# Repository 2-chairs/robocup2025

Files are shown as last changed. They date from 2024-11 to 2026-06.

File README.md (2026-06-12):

# robocup2025
# Team 2-Chairs - RoboCup Singapore Soccer Open Junior 

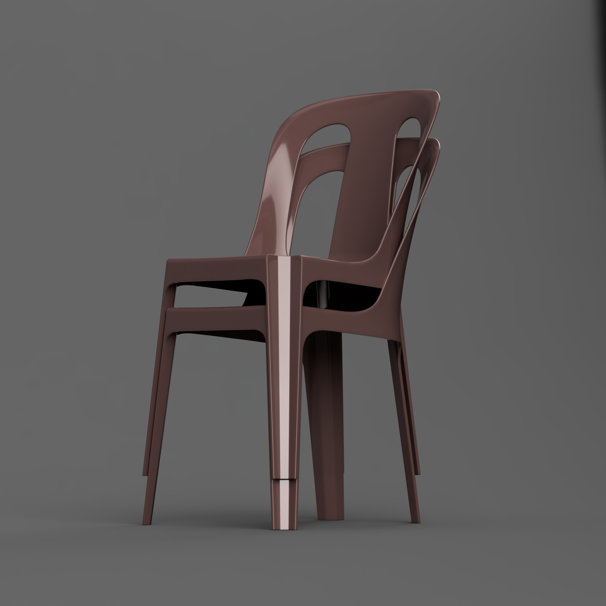
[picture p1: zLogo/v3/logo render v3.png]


*Repository for the official electronic, mechanical, and software files of Team 2-Chairs.*

## About

This repository is for **Team 2-Chairs**, a Singapore RoboCup Open Soccer Junior team, and includes relevant design files and resources.

## Repository Structure

- **Electronics/** - PCB designs, schematics, and component footprints. (Note: regarding layer1 and layer3 pcb files, a critical mistake had been made where the Xiao Esp32c3 was powered through 3v3 pin with 3v3, when it should have been through 5v VIN pin with 5v; regarding layer3 the camera should be powered through 5v instead of 3v3 too)
- **Mechanical/** - 3D-printable files in **.3MF** and **.STL** formats; includes rendered images of the robot and its mirrored counterpart for reference. 
- **Code/** - Firmware and control software for the robot. (sub-par quality, some code untested)
- **Logo/** - Official team branding and design assets.

## Credits 
In the grand tapestry of our design endeavor, we owe a debt of profound gratitude to the esteemed teams of Sentinels Robotics, ducc. & Butter Chicken, whose brilliant schematics and designs (and potentially code) have guided our efforts.

## License & Copyright

© 2025 Team 2-Chairs. All rights reserved, except where otherwise stated. 

<p xmlns:cc="http://creativecommons.org/ns#" ><a rel="cc:attributionURL" href="https://github.com/2-chairs/robocup2025">This work</a> by <span property="cc:attributionName">Ng Chen-Xuan, Euston Tan, Chen YiKai</span> is licensed under <a href="https://creativecommons.org/licenses/by-nc-sa/4.0/?ref=chooser-v1" target="_blank" rel="license noopener noreferrer" style="display:inline-block;">Creative Commons Attribution-NonCommercial-ShareAlike 4.0 International</a></p>

---

**"Two chairs, twice the betterness"**

*Written by ChatGPT, Edited by human*

<p>Retired as of 6 April 2025</p>

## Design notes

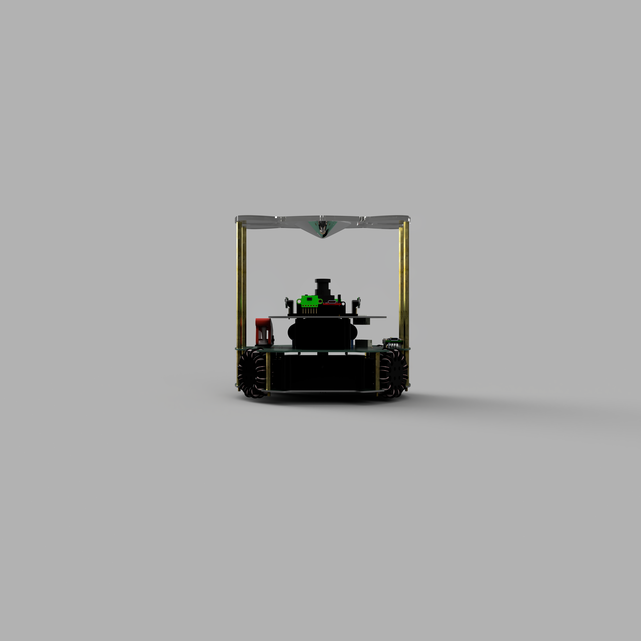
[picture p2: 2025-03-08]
Mechanical/Renders/one more bot v220 pic.png

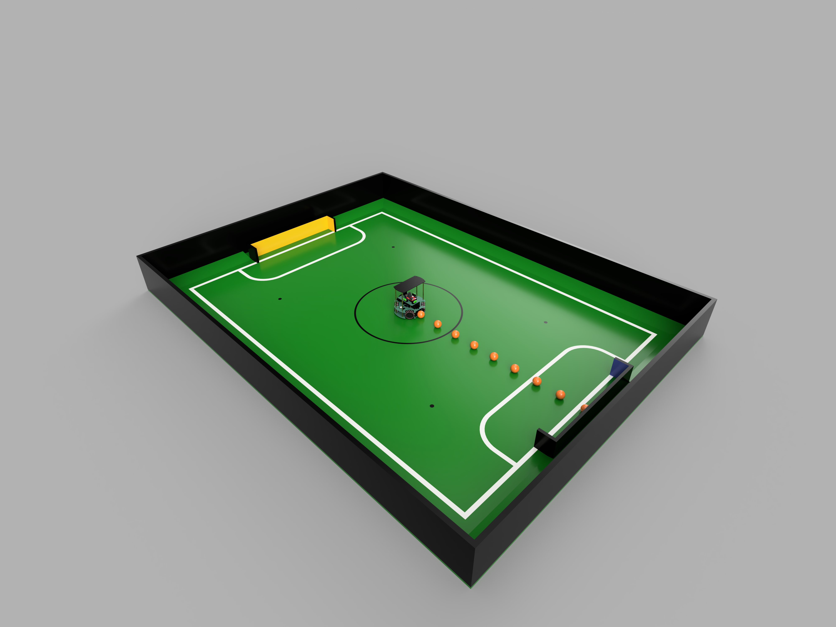
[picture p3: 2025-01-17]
Mechanical/Renders/bot_and_playfield.png

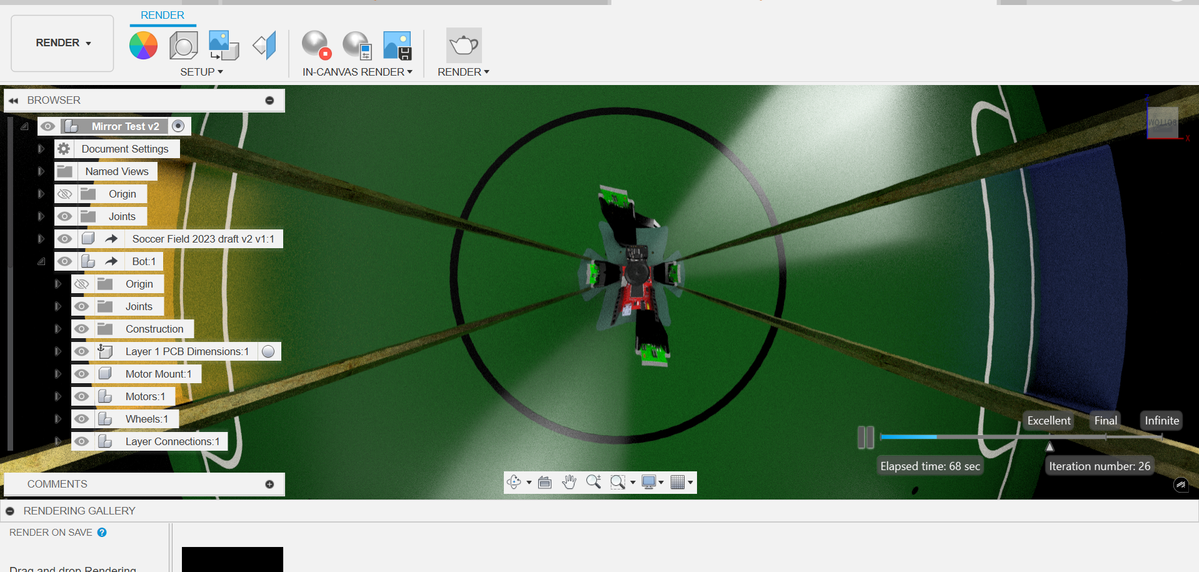
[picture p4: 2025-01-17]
Mechanical/Renders/Mirror/Mirror simulation screenshot.png

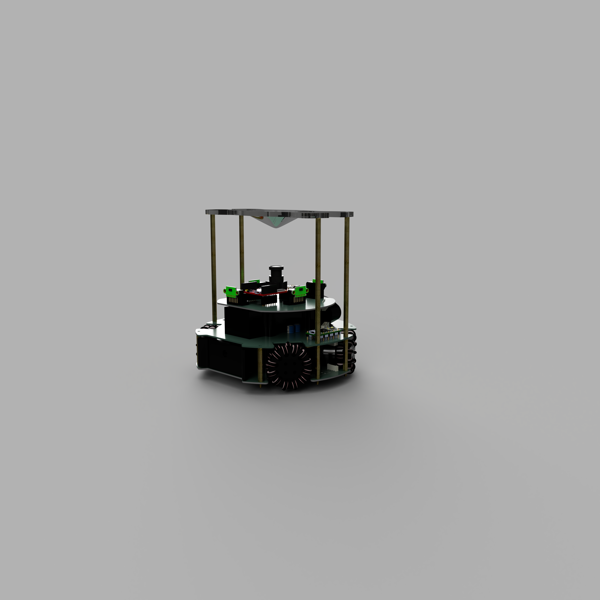
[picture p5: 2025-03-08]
Mechanical/Renders/another bot v220 pic.png

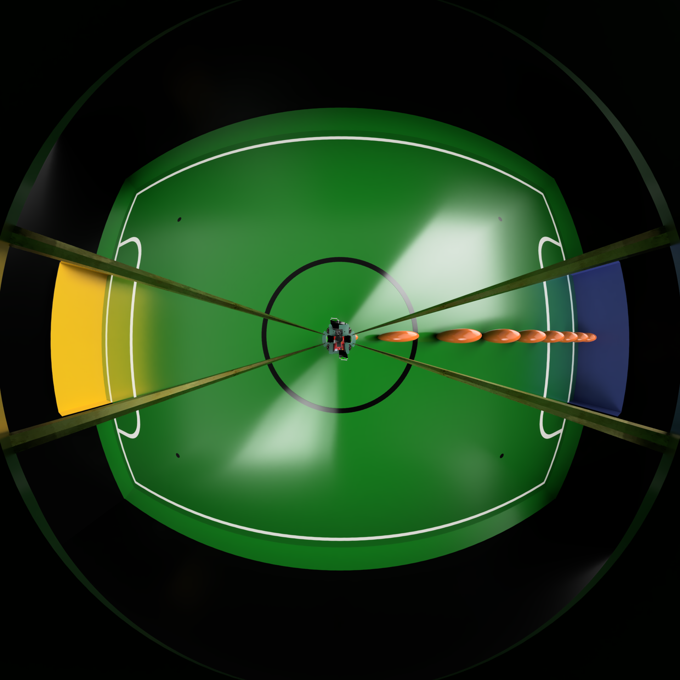
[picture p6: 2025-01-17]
Mechanical/Renders/Mirror/mirrortest3.png

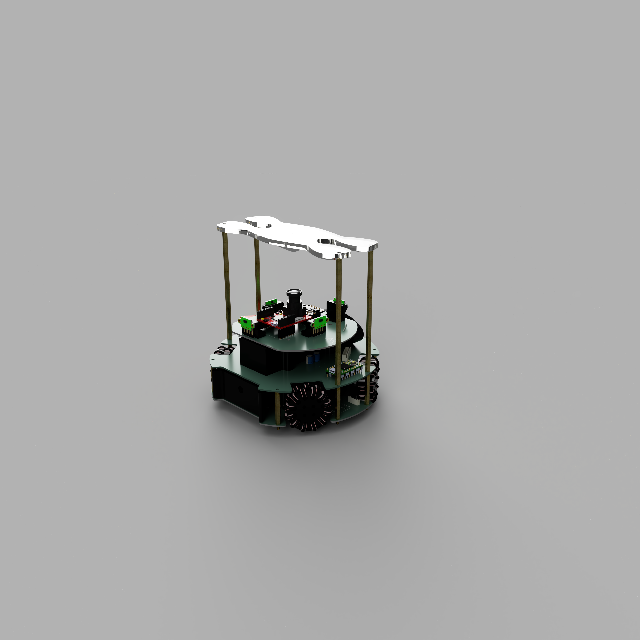
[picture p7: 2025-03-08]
Mechanical/Renders/bot v220 pic.png

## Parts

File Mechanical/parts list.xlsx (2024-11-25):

Parts list
Part type | About | Specification | Material | Manufactoring method | Dimensions/mm (If applicable) | Price/single qty | Price/buying qty | buying qty/bag | qty needed | buying qty | Total price | Buying link
O Rings | o rings as tyres for moniwheel rollers | v cool | nitrile rubber | idk just buying it | OD: 9.3, ID: 6.1, Thickness: 1.6 | 0.121 | 6.07 | 50 | 360 | 8 | 48.56 | https://sg.rs-online.com/web/p/gaskets-o-rings/0128811?gb=s
Dowel Pins | Pin to act as axel for omniwheel rollers | who cares | 304 Stainless Steel | not my problem | Diameter: 2, Length: 6 | 0.06 | 3 | 50 | 360 | 8 | 24 | https://www.lazada.sg/products/nindejin-5-50pcs-dowel-pins-304-stainless-steel-m2-m25-m3-m4-m5-m6-parallel-pins-fastener-solid-cylinder-pin-gb119-i1940710543-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
Motors | driving motors duh? | Chihai motors (CHR-GM25-370) | not our problem proably metals n stuff | actually though whats this column for |  | 12.08 | 12.08 | 1 | 9 | 9 | 108.72 | https://www.aliexpress.com/item/4000981259486.html?utparam-url=scene%3Asearch%7Cquery_from%3A

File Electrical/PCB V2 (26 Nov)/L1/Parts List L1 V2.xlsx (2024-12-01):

Parts list | status
Part |  | Model | Package | Weight | Dimensions (LxWxH) in mm | Price | Data Sheet
MCU for L1 | not required to buy | XIAO 102010428 | NA | no clue |  | not required as in lab
Photoresistor | to buy | ALS-PT19-315C/L177/TR8 | NA | refer to ducc | 0.8 x 0.6 x 1.7 | $0.05
LEDS | lab | kicad smd thingy | NA | NA | 1.6mm x 0.8mm x 0.6 mm | 0.05( actl 0 cos lab have)
Muxes | to buy | CD74HC4067SM |  |  | 7.4 X 6 X 1.4 | 2.0 to 4 | https://www.snapeda.com/parts/CD74HC4067SM96G4/Texas%20Instruments/datasheet/

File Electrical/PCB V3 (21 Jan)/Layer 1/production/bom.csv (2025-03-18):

Designator | Footprint | Quantity | Value | LCSC Part #
C1, C10, C11, C12, C13, C14, C15, C16, C17, C18, C19, C2, C20, C21, C22, C23, C24, C25, C26, C27, C28, C29, C3, C30, C31, C32, C4, C5, C6, C7, C8, C9 | 0603 | 32 | 1uF
C33, C34 | 0603 | 2 | .1uF
C35 | 0603 | 1 | 0.1uF | C3011705
C36 | CP_Radial_D8.0mm_P3.50mm | 1 | 100uF | C249586
C37, C38, C39, C41, C42, C43 | CP_Radial_D16.0mm_P7.50mm | 6 | 1000uF | C249586
C40 | 0603 | 1 | 0.68uF | C59782
C44 | 0603 | 1 | 1500pF | C107060
D1 | D_DO-201AD_P15.24mm_Horizontal | 1 | 1N5401 | C179506
D2 | TO-220-2_Vertical | 1 | MBR745
J1 | JST_EH_B4B-EH-A_1x04_P2.50mm_Vertical | 1 | Conn_01x04
J2 | AMASS_XT30UPB-M_1x02_P5.0mm_Vertical | 1 | Conn_01x02
L33 | L_APV_APH1040 | 1 | 33uH | C2875750
LED1, LED10, LED11, LED12, LED13, LED14, LED15, LED16, LED17, LED18, LED19, LED2, LED20, LED21, LED22, LED23, LED24, LED25, LED26, LED27, LED28, LED29, LED3, LED30, LED31, LED32, LED4, LED5, LED6, LED7, LED8, LED9 | LED_PLCC_2835 | 32 | WHITE 3528
LED_1, LED_10, LED_11, LED_12, LED_13, LED_14, LED_15, LED_16, LED_17, LED_18, LED_19, LED_2, LED_20, LED_21, LED_22, LED_23, LED_24, LED_25, LED_26, LED_27, LED_28, LED_29, LED_3, LED_30, LED_31, LED_32, LED_4, LED_5, LED_6, LED_7, LED_8, LED_9 | XDCR_ALS-PT19-315C_L177_TR8 | 32 | R_Photo
Q2 | TO-220-3_Vertical | 1 | STP75NF75 | C13678
Q4 | SOT95P237X112-3N | 1 | IRLML6344TRPBF
R1, R10, R11, R12, R13, R14, R15, R16, R17, R18, R19, R2, R20, R21, R22, R23, R24, R25, R26, R27, R28, R29, R3, R30, R31, R32, R4, R5, R6, R7, R8, R9 | 0603 | 32 | 0R39
R33, R34 | 0603 | 2 | 3k24
R35 | 0603 | 1 | 36.9K/56k | C23082
R36 | 0603 | 1 | 2K/2.94k | C22843
R37, R43 | 0603 | 2 | 10k
R38 | 0603 | 1 | 3K | C137748
R39 | 0603 | 1 | 10K | C25804
R40 | 0603 | 1 | 470R | C21190
R41 | 0603 | 1 | 1K | C21190
R42 | 0603 | 1 | 20R | C22950
TP1 | testpoint_2pad_2-chairs. | 1 | Led 3v3 & Gnd TP
U1 | VREG_TPS79625KTTR | 1 | LM2587S-ADJ
U2, U3 | SOP65P780X200-24N | 2 | CD74HC4067SM
U4 | AMASS_XT30U-M_1x02_P5.0mm_Vertical | 1 | XT30UPB-M
U5 | XiaoSeeedStudioEsp32 | 1 | 113991054

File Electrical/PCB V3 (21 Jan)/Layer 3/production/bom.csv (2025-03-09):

Designator | Footprint | Quantity | Value | LCSC Part #
J1, J3, J4, J5 | PinHeader_1x06_P2.54mm_Vertical | 4 | Conn_01x06
J2 | JST_XH_B8B-XH-A_1x08_P2.50mm_Vertical | 1 | Conn_02x08_Odd_Even
R1, R2, R3, R4, R5, R6, R7, R8 | 0603 | 8 | R
U1 | OPENMV_M7 | 1 | ~
U2 | MODULE_113991054 | 1 | 113991054
U3 | MODULE_4754 | 1 | 4754

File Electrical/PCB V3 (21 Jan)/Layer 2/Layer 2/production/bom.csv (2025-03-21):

Designator | Footprint | Quantity | Value | LCSC Part #
A1 | MODULE_DEV-15583 | 1 | TEENSY_4.0
C1, C2 | 0603 | 2 | 10u
C10, C14, C4, C7 | CP_Radial_D8.0mm_P3.50mm | 4 | 470u | C5162352
C3, C6 | 0603 | 2 | 10n
C5, C8 | CP_EIA-7343-15_Kemet-W_Pad2.25x2.55mm_HandSolder | 2 | 220u
D1, D2 | DIOM5025X220N | 2 | SS54
J1 | AMASS_XT60-M | 1 | XT60-M
J2 | JST_XH_B8B-XH-A_1x08_P2.50mm_Vertical | 1 | Conn_02x04_Odd_Even
J3 | JST_XH_B4B-XH-A_1x04_P2.50mm_Vertical | 1 | Conn_01x04
J5 | SolderWire-0.1sqmm_1x02_P3.6mm_D0.4mm_OD1mm | 1 | Conn_01x02
L1, L2 | 0630 One Piece Inductor | 2 | 15uH
Q1, Q2, Q3, Q4 | 8-DFN (5x6) | 4 | AON6354
R1, R12, R13, R2, R20, R21, R29, R30 | res0603 | 8 | 3K3
R10, R28 | 0603 | 2 | 10K
R11 | 0603 | 1 | 5k9
R14, R22, R3, R31 | res0603 | 4 | 10K
R15, R16, R17, R18, R19, R23, R24, R25, R26, R27, R32, R33, R34, R35, R36, R38, R4, R5, R6, R7, R8 | res0603 | 21 | 1K
R37 | 0603 | 1 | 3K24
SW2 | AMASS_XT30PW-M_1x02_P2.50mm_Horizontal | 1 | SW_SPST
SW3 | JST_XH_B2B-XH-A_1x02_P2.50mm_Vertical | 1 | SW_SPST
TP1 | 14 AWG Testpoint (Compact) | 1 | TestPoint_2Pole
TP2, TP3 | 14 AWG Testpoint (Vertical) | 2 | TestPoint_2Pole
U1, U12, U5, U9 | fixed -onenew-newer-newest | 4 | VNH5019ATR-E
U2, U3 | TI_SO-PowerPAD-8 | 2 | TPS5430DDAG4
U4, U6, U7, U8 | XT30UPB-M | 4 | XT30UPB-M

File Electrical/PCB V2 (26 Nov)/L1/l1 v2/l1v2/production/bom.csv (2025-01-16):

Designator | Footprint | Quantity | Value | LCSC Part #
C1, C10, C11, C12, C13, C14, C15, C16, C17, C18, C19, C2, C20, C21, C22, C23, C24, C25, C26, C27, C28, C29, C3, C30, C31, C32, C4, C5, C6, C7, C8, C9 | 0603 | 32 | 1uF
J1 | SolderWirePad_1x01_SMD_1x2mm | 1 | Conn_01x01_Socket
J2 | SolderWire-0.5sqmm_1x01_D0.9mm_OD2.1mm | 1 | Conn_01x01_Socket
J3 | PinHeader_1x02_P1.00mm_Horizontal | 1 | Conn_01x02
L1, L10, L11, L12, L13, L14, L15, L16, L17, L18, L19, L2, L20, L21, L22, L23, L24, L25, L26, L27, L28, L29, L3, L30, L31, L32, L4, L5, L6, L7, L8, L9 | 0805 | 32 | 10µH
LED1, LED10, LED11, LED12, LED13, LED14, LED15, LED16, LED17, LED18, LED19, LED2, LED20, LED21, LED22, LED23, LED24, LED25, LED26, LED27, LED28, LED29, LED3, LED30, LED31, LED32, LED4, LED5, LED6, LED7, LED8, LED9 | LED_PLCC_2835 | 32 | WHITE 3528
LED_1, LED_10, LED_11, LED_12, LED_13, LED_14, LED_15, LED_16, LED_17, LED_18, LED_19, LED_2, LED_20, LED_21, LED_22, LED_23, LED_24, LED_25, LED_26, LED_27, LED_28, LED_29, LED_3, LED_30, LED_31, LED_32, LED_4, LED_5, LED_6, LED_7, LED_8, LED_9 | XDCR_ALS-PT19-315C_L177_TR8 | 32 | R_Photo
R1, R10, R11, R12, R13, R14, R15, R16, R17, R18, R19, R2, R20, R21, R22, R23, R24, R25, R26, R27, R28, R29, R3, R30, R31, R32, R4, R5, R6, R7, R8, R9 | 0603 | 32 | 0R39
SW1 | Nidec_Copal_CAS-120A | 1 | SW_SPDT
TP1, TP2 | TestPoint_2Pads_Pitch2.54mm_Drill0.8mm | 2 | TestPoint
U1 | MCU_Seeed_ESP32C3 | 1 | 102010428
U2, U3 | SOP65P780X200-24N | 2 | CD74HC4067SM
U4 | XT30UPB-M | 1 | XT30UPB-M

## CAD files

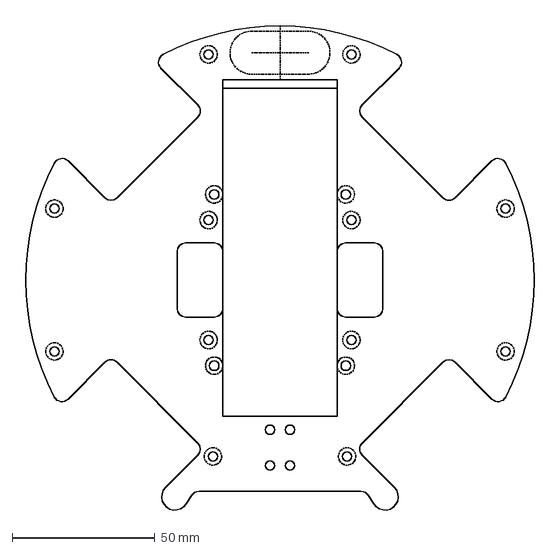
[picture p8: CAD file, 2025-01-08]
Electrical/PCB V2 ( 26 Nov)/L2/L2 Layout.dxf
184.7 x 173.1 mm

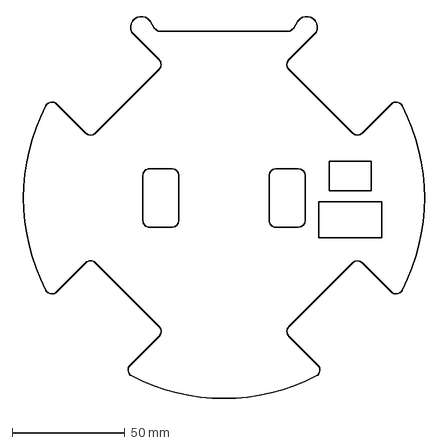
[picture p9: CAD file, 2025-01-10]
Electrical/PCB V2 (26 Nov)/L2/L2 Edgecut DXF.dxf
184.7 x 173.1 mm

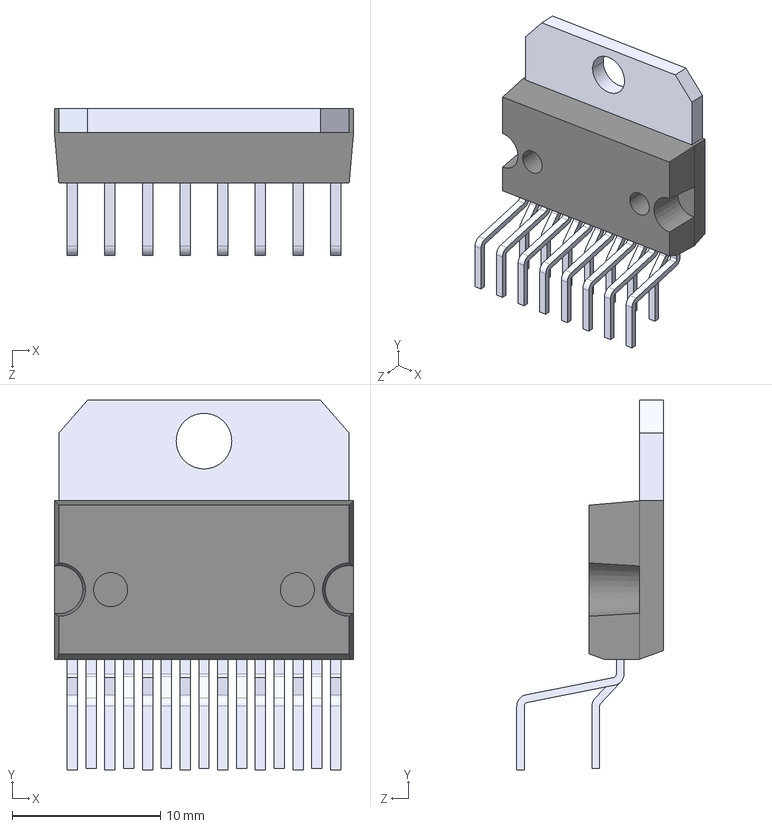
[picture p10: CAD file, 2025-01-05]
Electrical/PCB V2 (26 Nov)/L2/References/L298N/L298N.step
20.2 x 25.0 x 9.89 mm

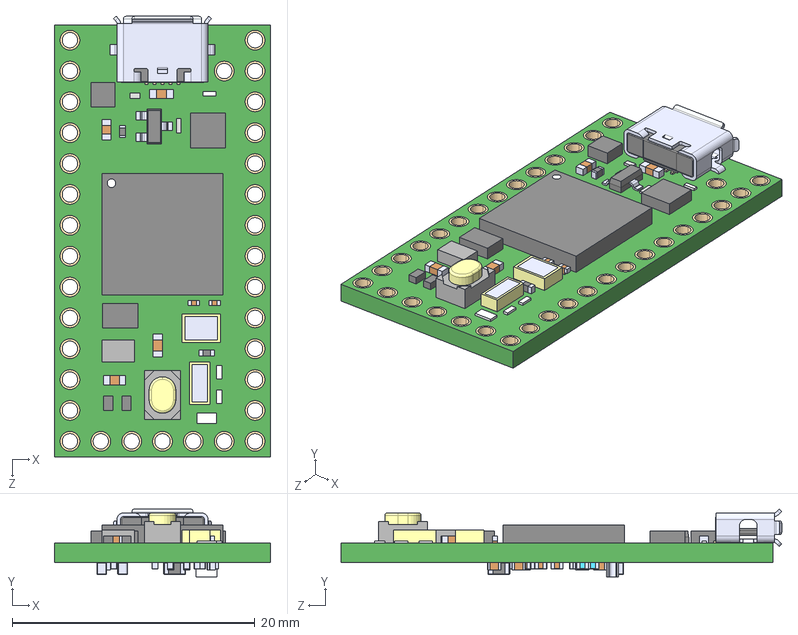
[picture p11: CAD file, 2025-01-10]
Electrical/PCB V2 (26 Nov)/L2/References/Teensy Symbol/DEV-15583.step
17.8 x 5.58 x 36.3 mm
DEV-15583 board
C5-C18 (0.55mm)
C20-C24 (0.65)
R1-R3 (0.4inch)_1269AS-H-3R3M=P2
L1^DEV-15583 ASS
C x 2
C2

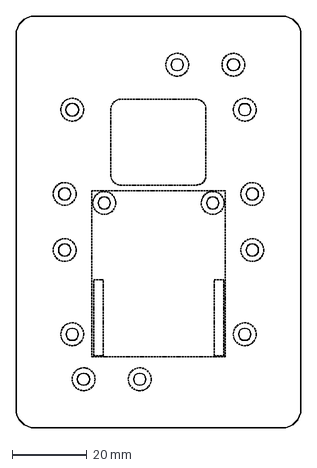
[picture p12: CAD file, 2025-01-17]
Electrical/PCB V2 (26 Nov)/L3/DXFs/Drawings/Drawings v0.dxf
76.1 x 110.0 mm

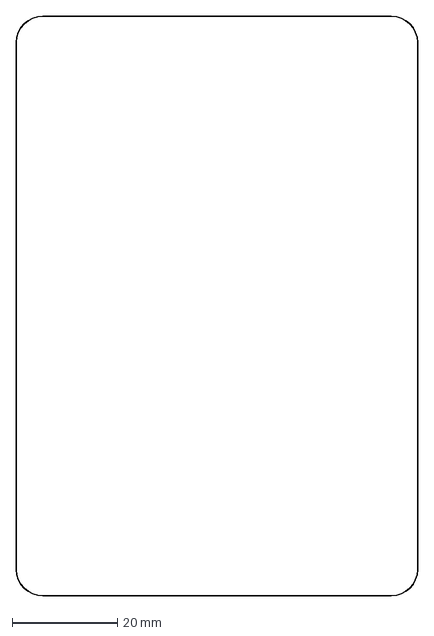
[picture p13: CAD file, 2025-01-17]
Electrical/PCB V2 (26 Nov)/L3/DXFs/Edgecuts/Edgecuts v0.dxf
76.1 x 110.0 mm

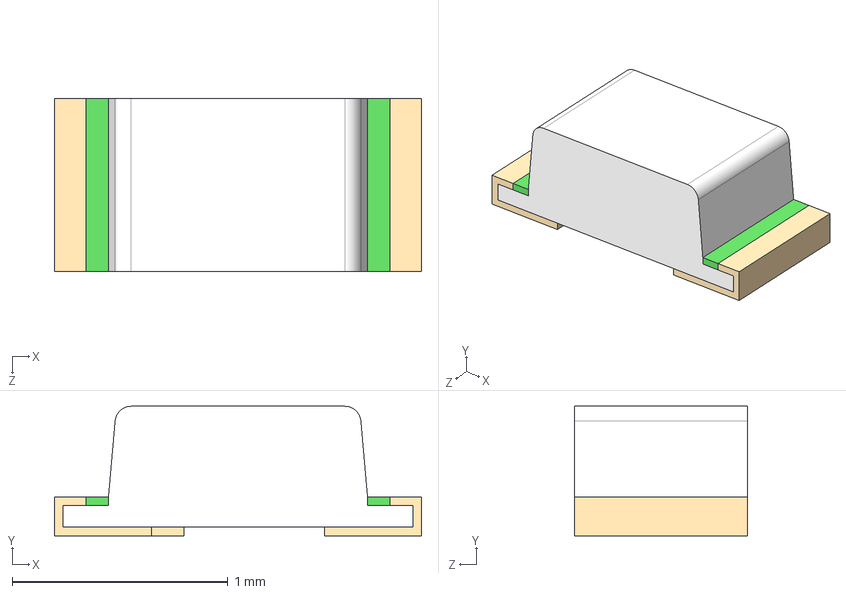
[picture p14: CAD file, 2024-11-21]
Electrical/PCB V2 (26 Nov)/References/ALS-PT19-315C_L177_TR8/ALS-PT19-315C_L177_TR8.step
1.70 x 0.6 x 0.8 mm

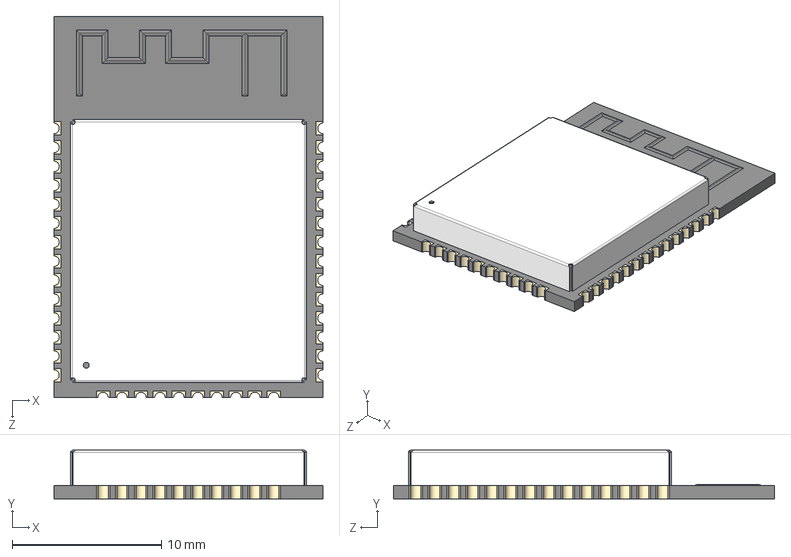
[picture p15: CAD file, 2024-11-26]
Electrical/PCB V2 (26 Nov)/References/ESP32-WROOM-32D-N4/ESP32-WROOM-32D-N4.step
18.0 x 3.25 x 25.5 mm

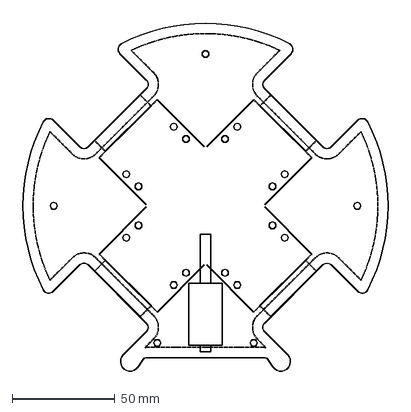
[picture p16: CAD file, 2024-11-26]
Electrical/PCB V2 (26 Nov)/References/L1 Layout.dxf
184.7 x 173.1 mm

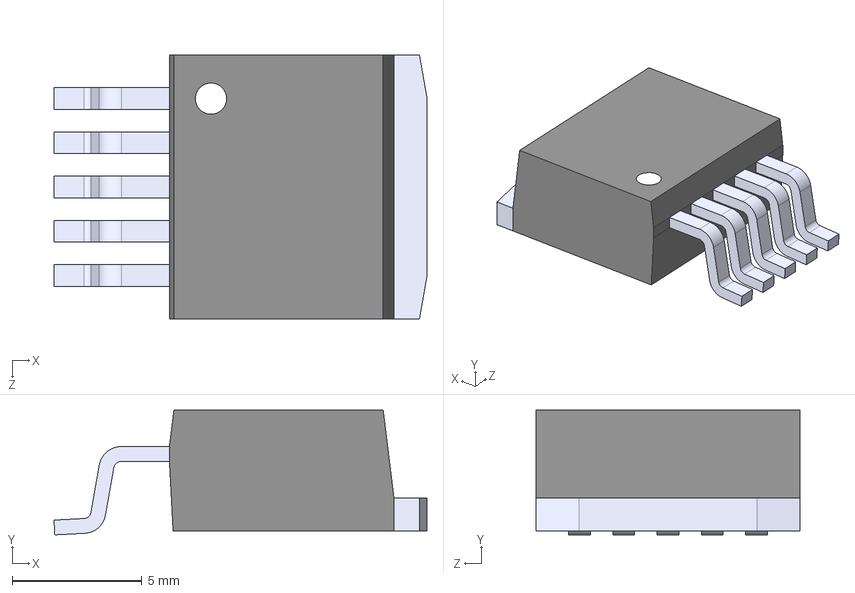
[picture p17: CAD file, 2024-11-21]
Electrical/PCB V2 (26 Nov)/References/LM2596ADJ/LM2596ADJ.step
14.4 x 4.80 x 10.2 mm

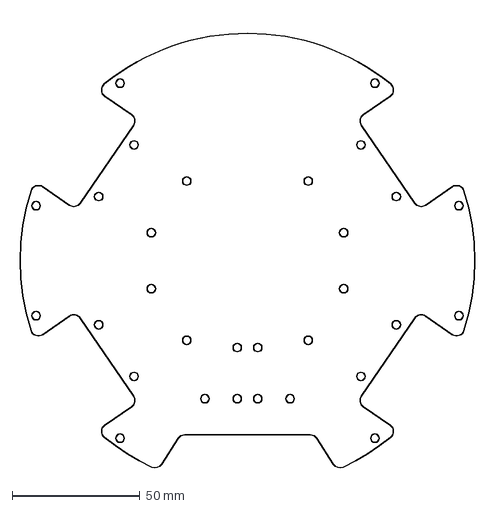
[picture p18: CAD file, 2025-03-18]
Electrical/PCB V3 (21 Jan)/Layer 1/Sub-References/OneAndOnlyDxf v10dxf.dxf
180.9 x 177.0 mm

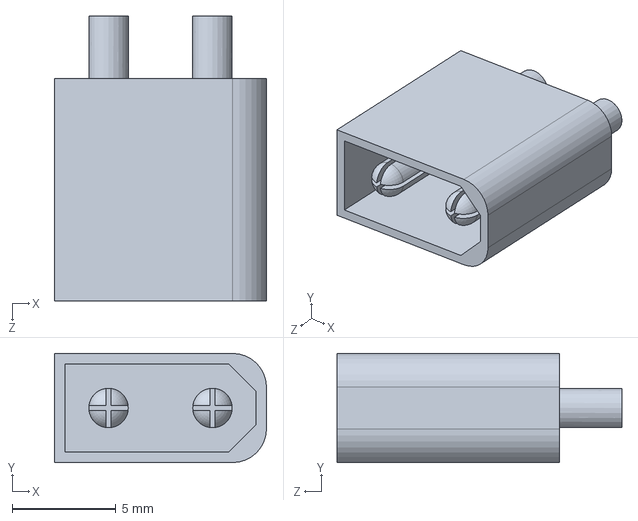
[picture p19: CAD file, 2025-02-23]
Electrical/PCB V3 (21 Jan)/Layer 1/Sub-References/xt30/xt30male/XT30U-M_NEW.SLDPRT
10.2 x 5.25 x 13.7 mm

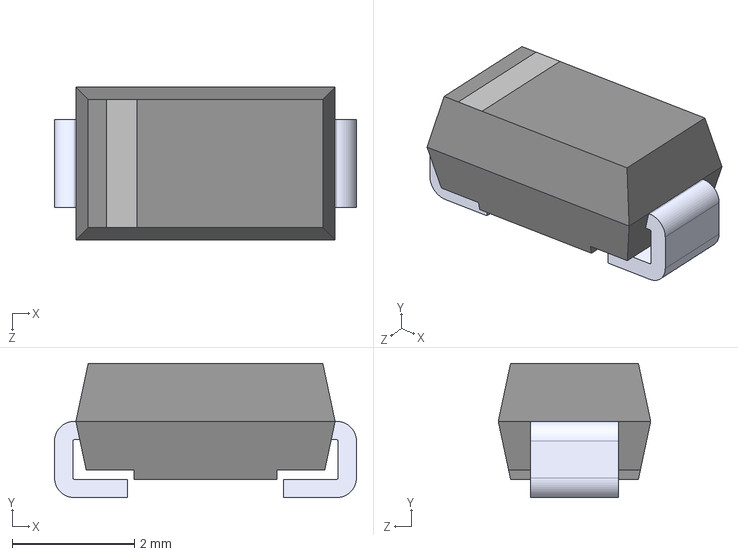
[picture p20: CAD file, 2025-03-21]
Electrical/PCB V3 (21 Jan)/Layer 2/Layer 2/3dmodels/SS54-HF.step
4.95 x 2.20 x 2.50 mm

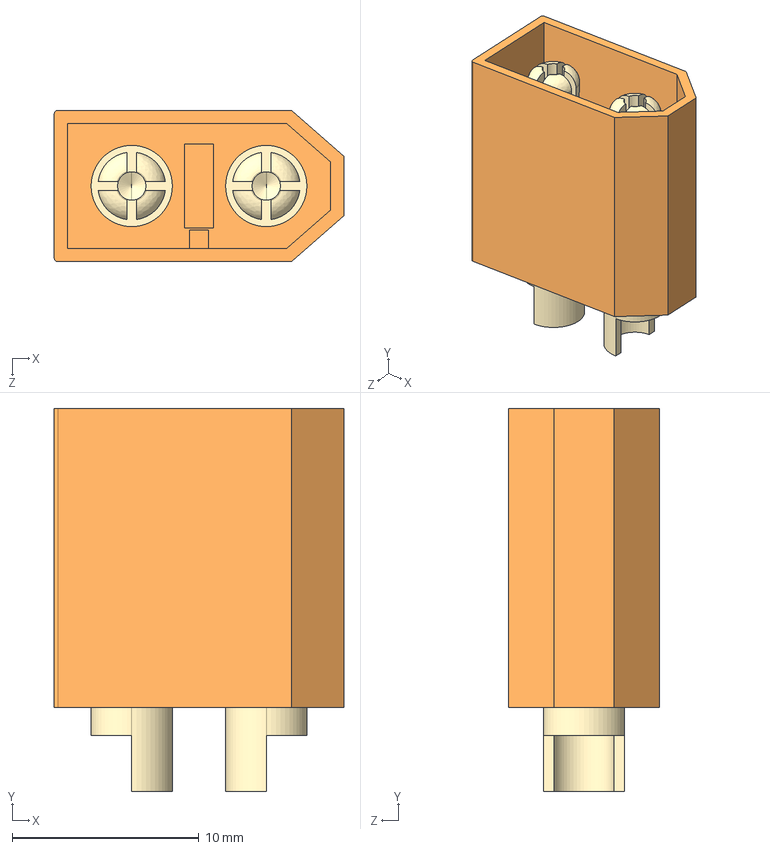
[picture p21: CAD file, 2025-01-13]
Electrical/PCB V3 (21 Jan)/Layer 2/Sub-References/amass/XT60-M--3DModel-STEP-510211.STEP
15.5 x 20.5 x 8.10 mm

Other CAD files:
Electrical/PCB V3 (21 Jan)/Layer 2/Sub-References/Capacitor/ECA2AM471B.STEP
Electrical/PCB V3 (21 Jan)/Layer 2/Sub-References/caps/Aluminum_electrolytic_capacitor_radial_D8_H11_PinD0.6_Pitch3.5_nominal_blue.step
Electrical/PCB V3 (21 Jan)/Layer 2/Sub-References/DXFs/OneAndOnlyDxf v19.dxf
Electrical/PCB V2 (26 Nov)/L2/L2 Layout (V2).dxf
Electrical/PCB V3 (21 Jan)/Layer 1/Sub-References/OneAndOnlyDxf v2.dxf
Electrical/PCB V3 (21 Jan)/Layer 1/Sub-References/OneAndOnlyDxf v3.dxf
Electrical/PCB V3 (21 Jan)/Layer 1/Sub-References/OneAndOnlyDxf v4.dxf
Electrical/PCB V3 (21 Jan)/Layer 1/Sub-References/OneAndOnlyDxf v5.dxf
Electrical/PCB V3 (21 Jan)/Layer 1/Sub-References/OneAndOnlyDxf v6.dxf
Electrical/PCB V3 (21 Jan)/Layer 1/Sub-References/OneAndOnlyDxf v7.dxf
Electrical/PCB V3 (21 Jan)/Layer 1/Sub-References/OneAndOnlyDxf v8.dxf
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

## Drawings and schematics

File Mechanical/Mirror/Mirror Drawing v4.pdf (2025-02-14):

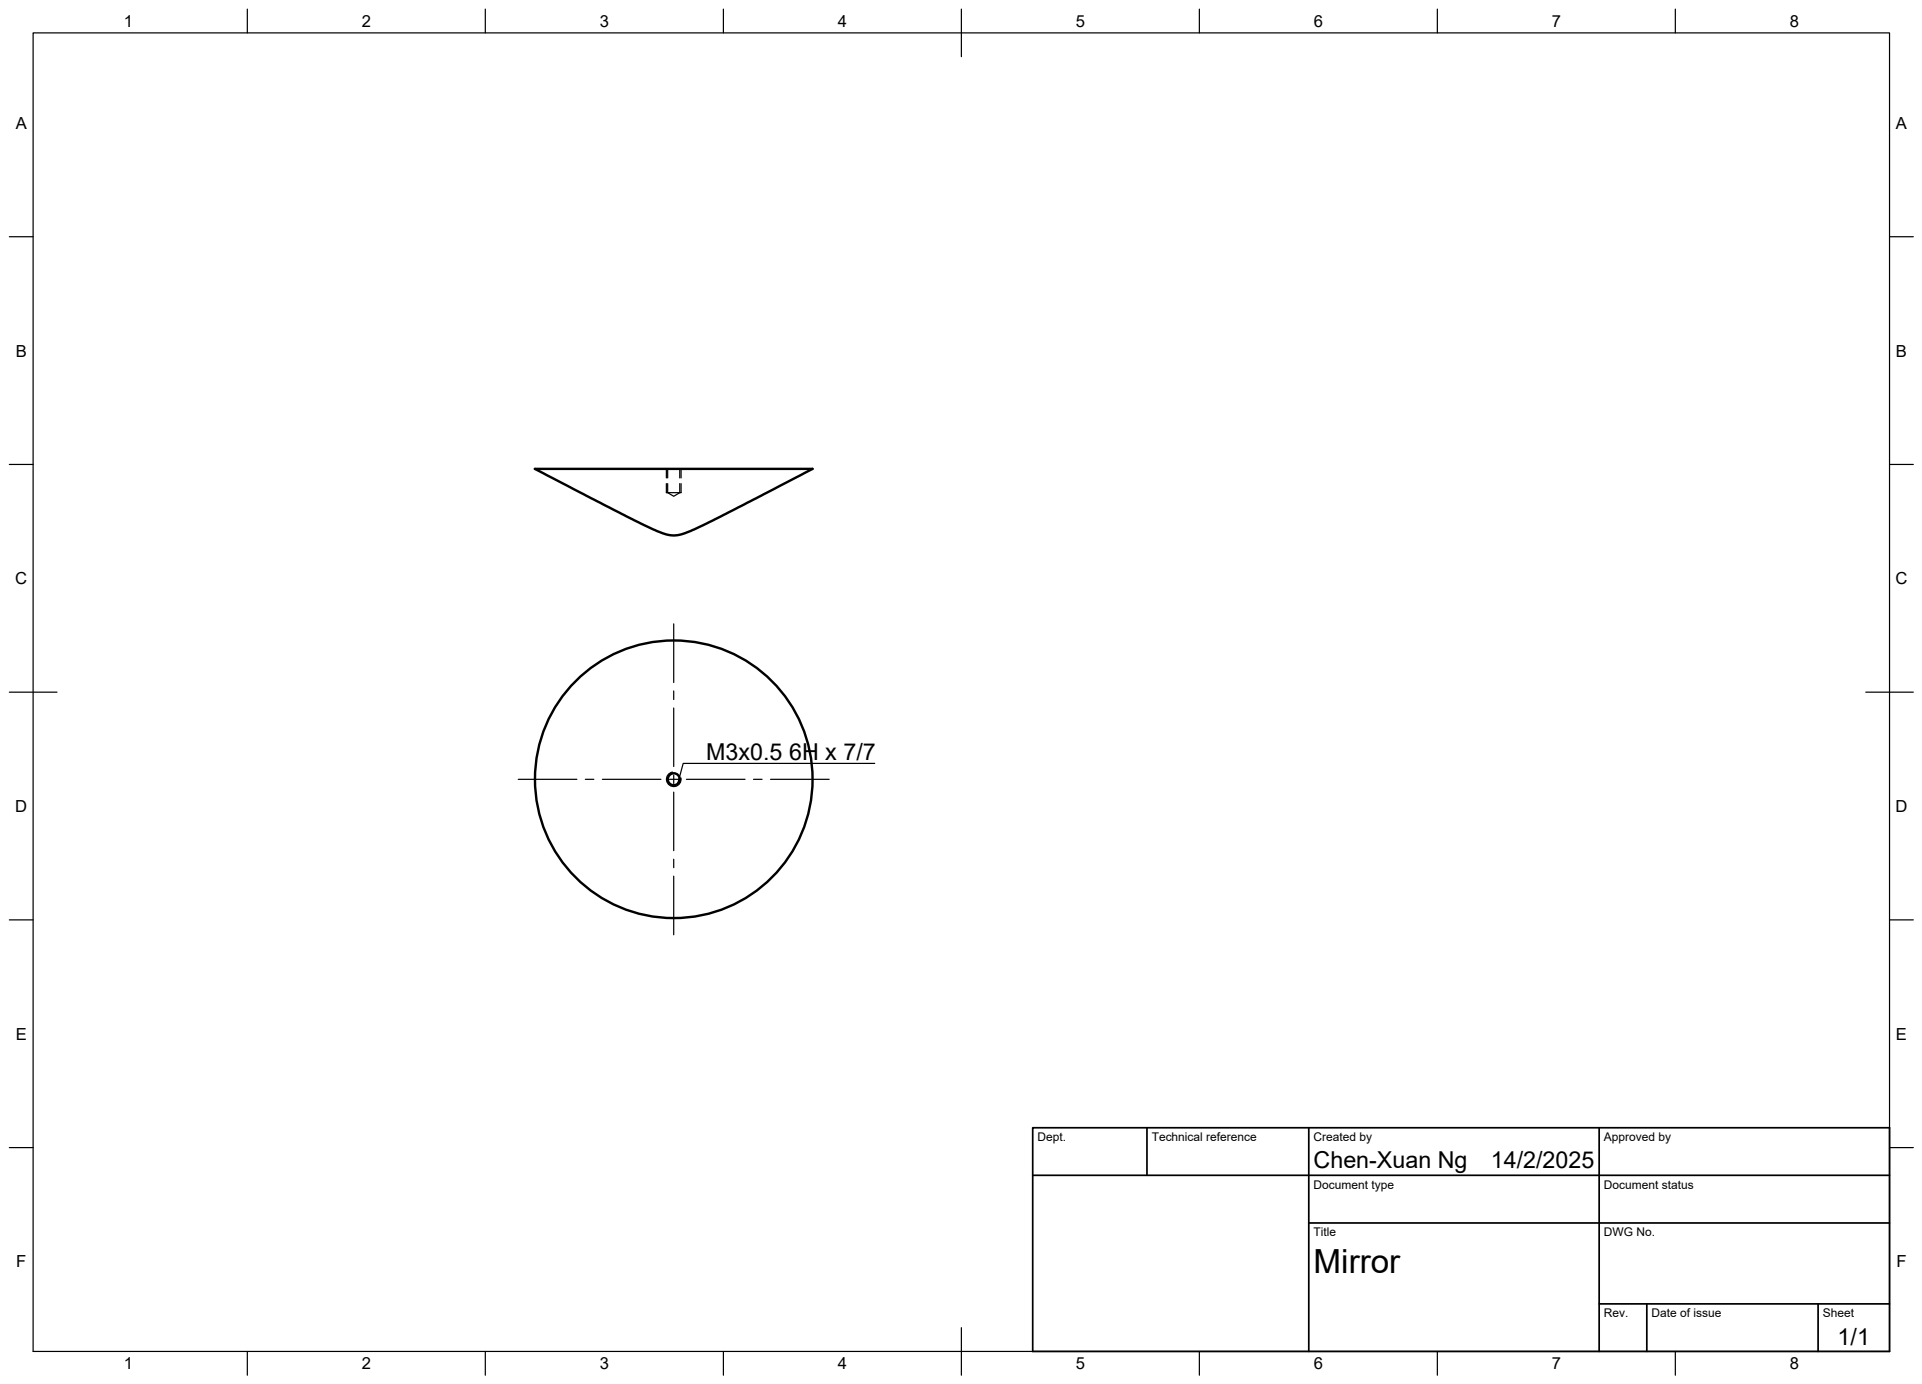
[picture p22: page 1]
Title; DWG No.; Rev.; Date of issue; Sheet

Dept. | Technical reference | Created by Chen-Xuan Ng 14/2/2025 | Approved by

Document type | Document status

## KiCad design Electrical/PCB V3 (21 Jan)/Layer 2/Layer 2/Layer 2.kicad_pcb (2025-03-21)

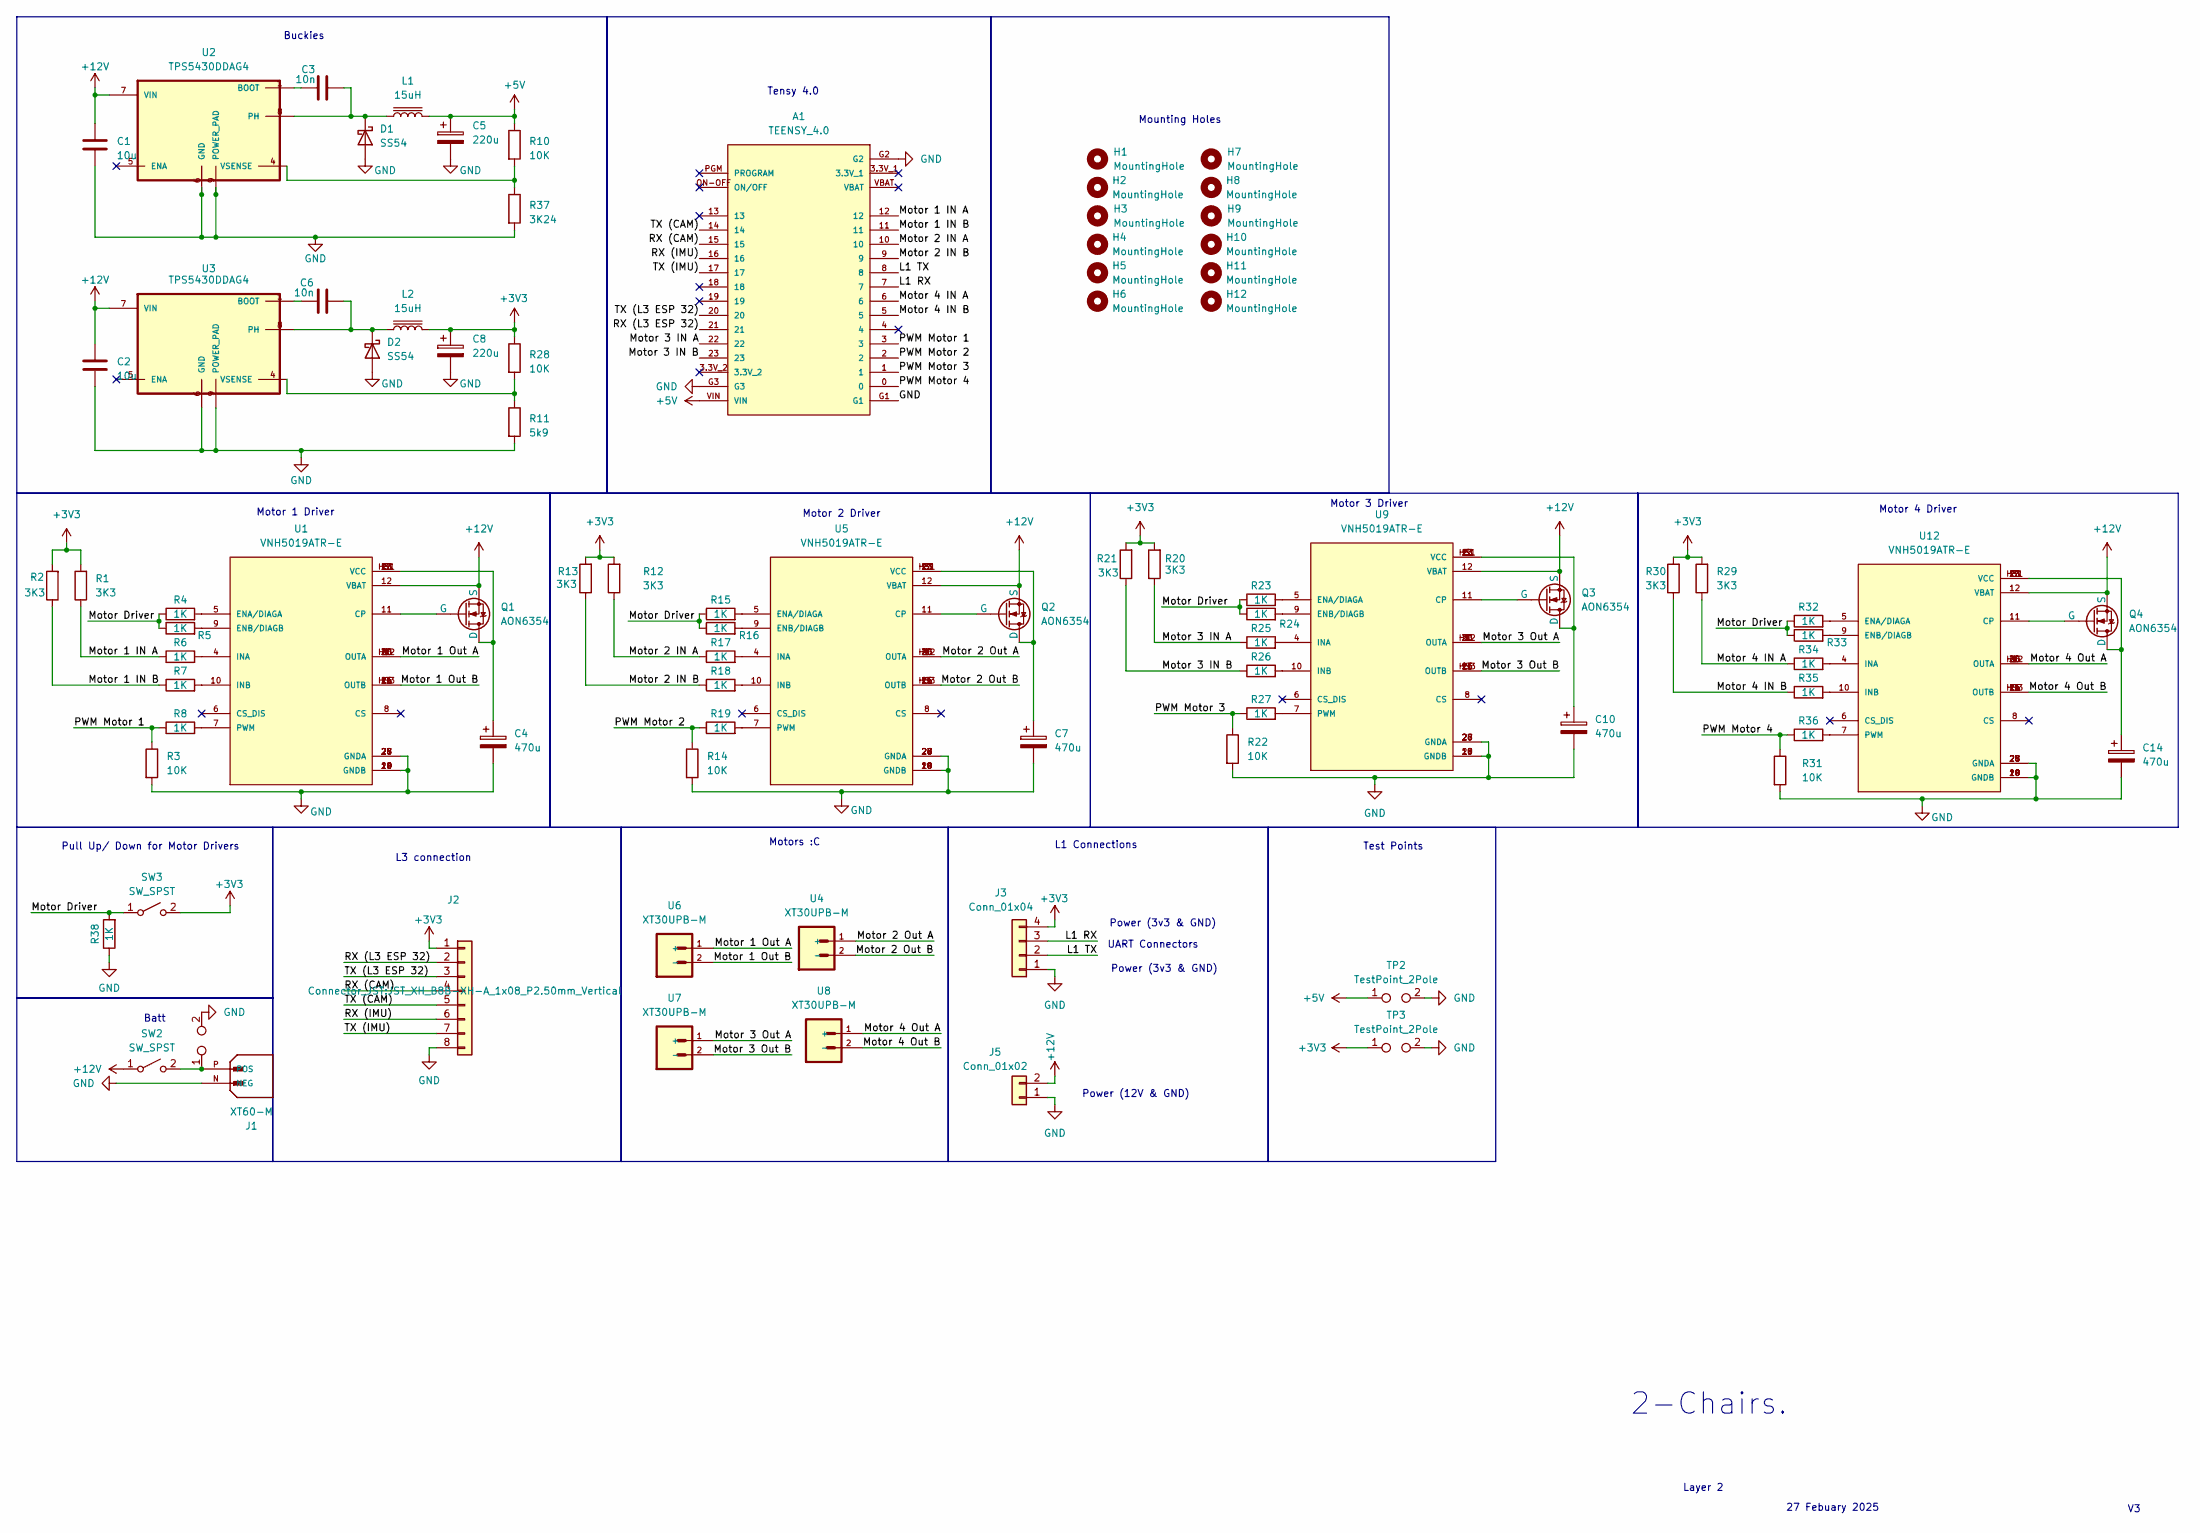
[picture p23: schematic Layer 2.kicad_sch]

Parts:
A1: TEENSY_4.0; MODULE_DEV-15583
C1, C2: 10u; C_0603_1608Metric
C3, C6: 10n; C_0603_1608Metric
C4, C7, C10, C14: 470u; CP_Radial_D8.0mm_P3.50mm; LCSC C5162352
C5, C8: 220u; CP_EIA-7343-15_Kemet-W_Pad2.25x2.55mm_HandSolder
D1, D2: SS54; DIOM5025X220N
H1, H2, H3, H4, H5, H6, H7, H8, H9, H10, H11, H12: MountingHole; MountingHole_3.2mm_M3_DIN965_Pad
J1: XT60-M; AMASS_XT60-M; PARTREV V1.2
J2: Conn_02x04_Odd_Even; JST_XH_B8B-XH-A_1x08_P2.50mm_Vertical
J3: Conn_01x04; JST_XH_B4B-XH-A_1x04_P2.50mm_Vertical
J5: Conn_01x02; SolderWire-0.1sqmm_1x02_P3.6mm_D0.4mm_OD1mm
L1, L2: 15uH; 0630 One Piece Inductor
Q1, Q2, Q3, Q4: AON6354; 8-DFN (5x6)
R1, R2, R12, R13, R20, R21, R29, R30: 3K3; res0603
R3, R14, R22, R31: 10K; res0603
R4, R5, R6, R7, R8, R15, R16, R17, R18, R19, R23, R24, R25, R26, R27, R32, R33, R34, R35, R36, R38: 1K; res0603
R10, R28: 10K; R_0603_1608Metric
R11: 5k9; R_0603_1608Metric
R37: 3K24; R_0603_1608Metric
SW2: SW_SPST; AMASS_XT30PW-M_1x02_P2.50mm_Horizontal
SW3: SW_SPST; JST_XH_B2B-XH-A_1x02_P2.50mm_Vertical
TP1: TestPoint_2Pole; 14 AWG Testpoint (Compact)
TP2, TP3: TestPoint_2Pole; 14 AWG Testpoint (Vertical)
U1, U5, U9, U12: VNH5019ATR-E; fixed -onenew-newer-newest; PARTREV 11
U2, U3: TPS5430DDAG4; TI_SO-PowerPAD-8
U4, U6, U7, U8: XT30UPB-M

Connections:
+3V3: C8.1, J2.1, J3.4, L2.2, R1.2, R2.2, R12.2, R13.2, R20.2, R21.2, R28.1, R29.2, R30.2, SW3.2 (B), TP3.1
+5V: A1.VIN, C5.1, L1.2, R10.1, TP2.1
+12V: C1.1, C2.1, J5.2, Q1.1 (S), Q1.2 (S), Q1.3 (S), Q2.1 (S), Q2.2 (S), Q2.3 (S), Q3.1 (S), Q3.2 (S), Q3.3 (S), Q4.1 (S), Q4.2 (S), Q4.3 (S), SW2.1 (A), U1.12 (VBAT), U2.7 (VIN), U3.7 (VIN), U5.12 (VBAT), U9.12 (VBAT), U12.12 (VBAT)
/L1 RX: A1.7, J3.3
/L1 TX: A1.8, J3.2
/Motor 1 IN A: A1.12, R1.1, R6.1
/Motor 1 IN B: A1.11, R2.1, R7.1
/Motor 1 Out A: U1.1 (OUTA), U1.25 (OUTA), U1.30 (OUTA), U1.HS2 (OUTA), U6.1 (+)
/Motor 1 Out B: U1.15 (OUTB), U1.16 (OUTB), U1.21 (OUTB), U1.HS3 (OUTB), U6.2 (-)
/Motor 2 IN A: A1.10, R12.1, R17.1
/Motor 2 IN B: A1.9, R13.1, R18.1
/Motor 2 Out A: U4.1 (+), U5.1 (OUTA), U5.25 (OUTA), U5.30 (OUTA), U5.HS2 (OUTA)
/Motor 2 Out B: U4.2 (-), U5.15 (OUTB), U5.16 (OUTB), U5.21 (OUTB), U5.HS3 (OUTB)
/Motor 3 IN A: A1.22, R20.1, R25.1
/Motor 3 IN B: A1.23, R21.1, R26.1
/Motor 3 Out A: U7.1 (+), U9.1 (OUTA), U9.25 (OUTA), U9.30 (OUTA), U9.HS2 (OUTA)
/Motor 3 Out B: U7.2 (-), U9.15 (OUTB), U9.16 (OUTB), U9.21 (OUTB), U9.HS3 (OUTB)
/Motor 4 IN A: A1.6, R29.1, R34.1
/Motor 4 IN B: A1.5, R30.1, R35.1
/Motor 4 Out A: U8.1 (+), U12.1 (OUTA), U12.25 (OUTA), U12.30 (OUTA), U12.HS2 (OUTA)
/Motor 4 Out B: U8.2 (-), U12.15 (OUTB), U12.16 (OUTB), U12.21 (OUTB), U12.HS3 (OUTB)
/Motor Driver: R4.1, R5.1, R15.1, R16.1, R23.1, R24.1, R32.1, R33.1, R38.2, SW3.1 (A)
/PWM Motor 1: A1.3, R3.1, R8.1
/PWM Motor 2: A1.2, R14.1, R19.1
/PWM Motor 3: A1.1, R22.1, R27.1
/PWM Motor 4: A1.0, R31.1, R36.1
/RX (CAM): A1.15, J2.4
/RX (IMU): A1.16, J2.6
/RX (L3 ESP 32): A1.21, J2.2
/TX (CAM): A1.14, J2.5
/TX (IMU): A1.17, J2.7
/TX (L3 ESP 32): A1.20, J2.3
GND: A1.G1, A1.G2, A1.G3, C1.2, C2.2, C4.2, C5.2, C7.2, C8.2, C10.2, C14.2, D1.2 (A), D2.2 (A), J1.N (NEG), J2.8, J3.1, J5.1, R3.2, R11.2, R14.2, R22.2, R31.2, R37.2, R38.1, TP1.2, TP2.2, TP3.2, U1.18 (GNDB), U1.19 (GNDB), U1.20 (GNDB), U1.26 (GNDA), U1.27 (GNDA), U1.28 (GNDA), U2.6 (GND), U2.9 (POWER_PAD), U3.6 (GND), U3.9 (POWER_PAD), U5.18 (GNDB), U5.19 (GNDB), U5.20 (GNDB), U5.26 (GNDA), U5.27 (GNDA), U5.28 (GNDA), U9.18 (GNDB), U9.19 (GNDB), U9.20 (GNDB), U9.26 (GNDA), U9.27 (GNDA), U9.28 (GNDA), U12.18 (GNDB), U12.19 (GNDB), U12.20 (GNDB), U12.26 (GNDA), U12.27 (GNDA), U12.28 (GNDA)
unnamed: C4.1, Q1.5 (D), Q1.6 (D), Q1.7 (D), Q1.8 (D), Q1.9 (D), U1.3 (VCC), U1.13 (VCC), U1.23 (VCC), U1.HS1 (VCC)
unnamed: C7.1, Q2.5 (D), Q2.6 (D), Q2.7 (D), Q2.8 (D), Q2.9 (D), U5.3 (VCC), U5.13 (VCC), U5.23 (VCC), U5.HS1 (VCC)
unnamed: C10.1, Q3.5 (D), Q3.6 (D), Q3.7 (D), Q3.8 (D), Q3.9 (D), U9.3 (VCC), U9.13 (VCC), U9.23 (VCC), U9.HS1 (VCC)
unnamed: C14.1, Q4.5 (D), Q4.6 (D), Q4.7 (D), Q4.8 (D), Q4.9 (D), U12.3 (VCC), U12.13 (VCC), U12.23 (VCC), U12.HS1 (VCC)
unnamed: C3.2, D1.1 (K), L1.1, U2.8 (PH)
unnamed: C6.2, D2.1 (K), L2.1, U3.8 (PH)
unnamed: J1.P (POS), SW2.2 (B), TP1.1
unnamed: Q1.4 (G), U1.11 (CP)
unnamed: Q2.4 (G), U5.11 (CP)
unnamed: Q3.4 (G), U9.11 (CP)
unnamed: Q4.4 (G), U12.11 (CP)
unnamed: R4.2, U1.5 (ENA/DIAGA)
unnamed: R5.2, U1.9 (ENB/DIAGB)
unnamed: R6.2, U1.4 (INA)
unnamed: R7.2, U1.10 (INB)
unnamed: R8.2, U1.7 (PWM)
unnamed: C3.1, U2.1 (BOOT)
unnamed: R10.2, R37.1, U2.4 (VSENSE)
unnamed: C6.1, U3.1 (BOOT)
unnamed: R11.1, R28.2, U3.4 (VSENSE)
unnamed: R15.2, U5.5 (ENA/DIAGA)
unnamed: R16.2, U5.9 (ENB/DIAGB)
unnamed: R17.2, U5.4 (INA)
unnamed: R18.2, U5.10 (INB)
unnamed: R19.2, U5.7 (PWM)
unnamed: R23.2, U9.5 (ENA/DIAGA)
unnamed: R24.2, U9.9 (ENB/DIAGB)
unnamed: R25.2, U9.4 (INA)
unnamed: R26.2, U9.10 (INB)
unnamed: R27.2, U9.7 (PWM)
unnamed: R32.2, U12.5 (ENA/DIAGA)
unnamed: R33.2, U12.9 (ENB/DIAGB)
unnamed: R34.2, U12.4 (INA)
unnamed: R35.2, U12.10 (INB)
unnamed: R36.2, U12.7 (PWM)

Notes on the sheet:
Tensy 4.0
Motor 4 Driver
Power (12V & GND)
Motor 1 Driver
Power (3v3 & GND)
Motor 3 Driver
L3 connection
UART Connectors
Motors :C
27 Febuary 2025
Test Points
Buckies
Motor 2 Driver
Mounting Holes
Layer 2
2-Chairs.
Pull Up/ Down for Motor Drivers
Batt
L1 Connections

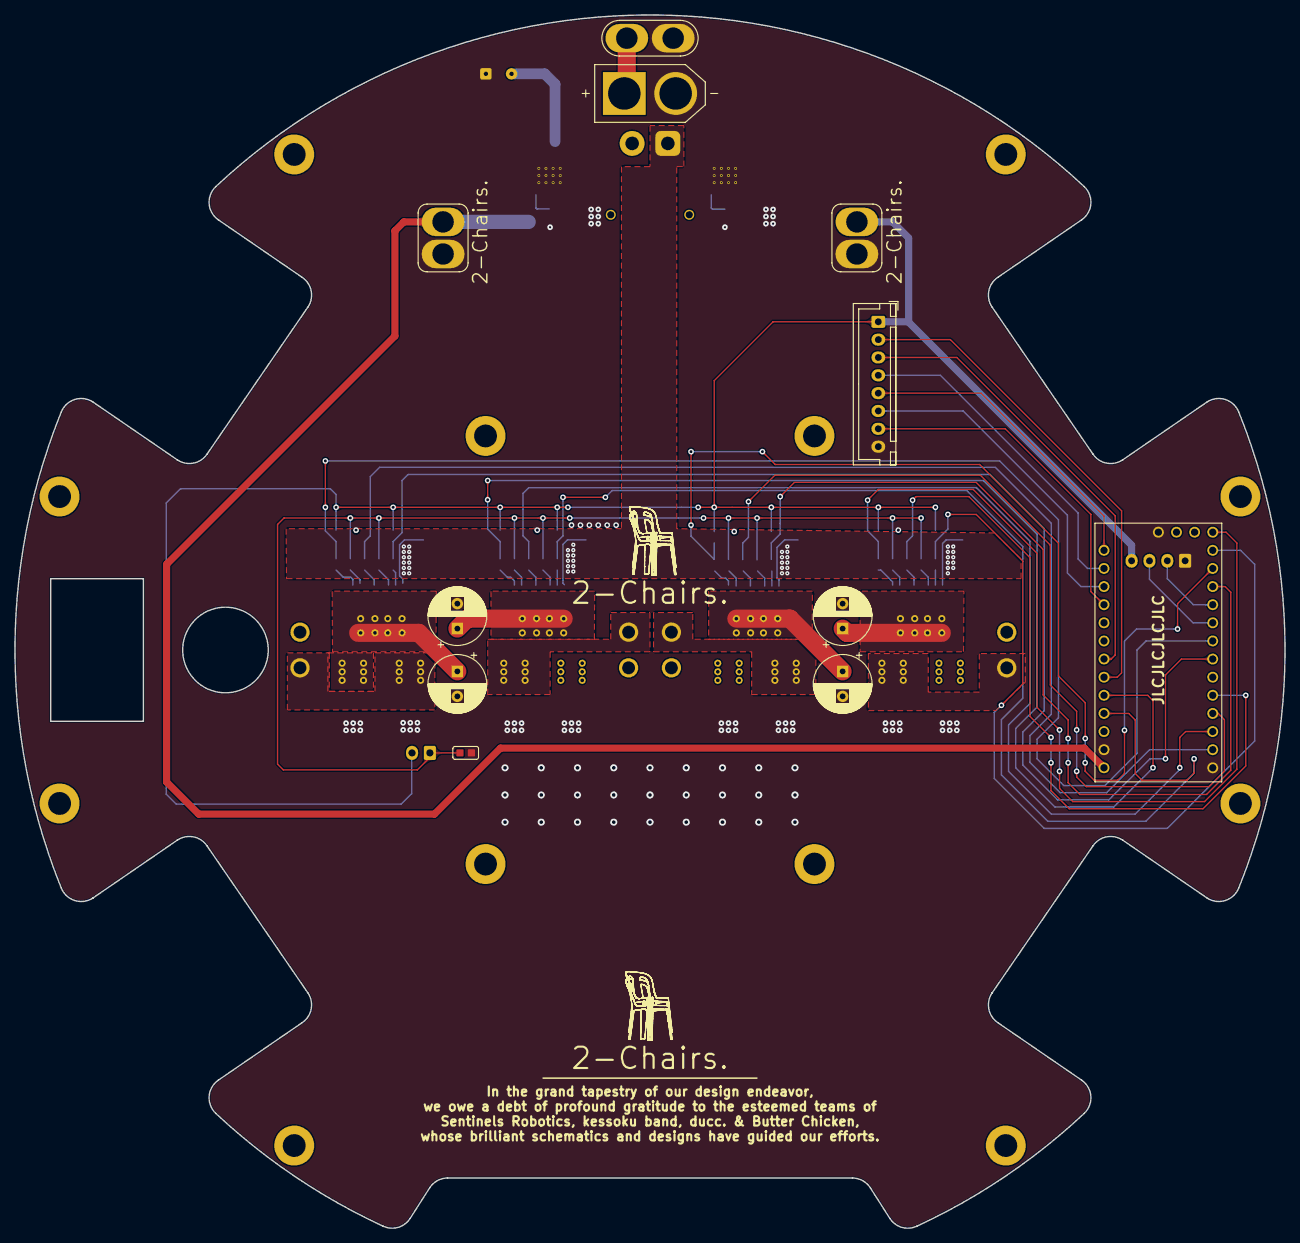
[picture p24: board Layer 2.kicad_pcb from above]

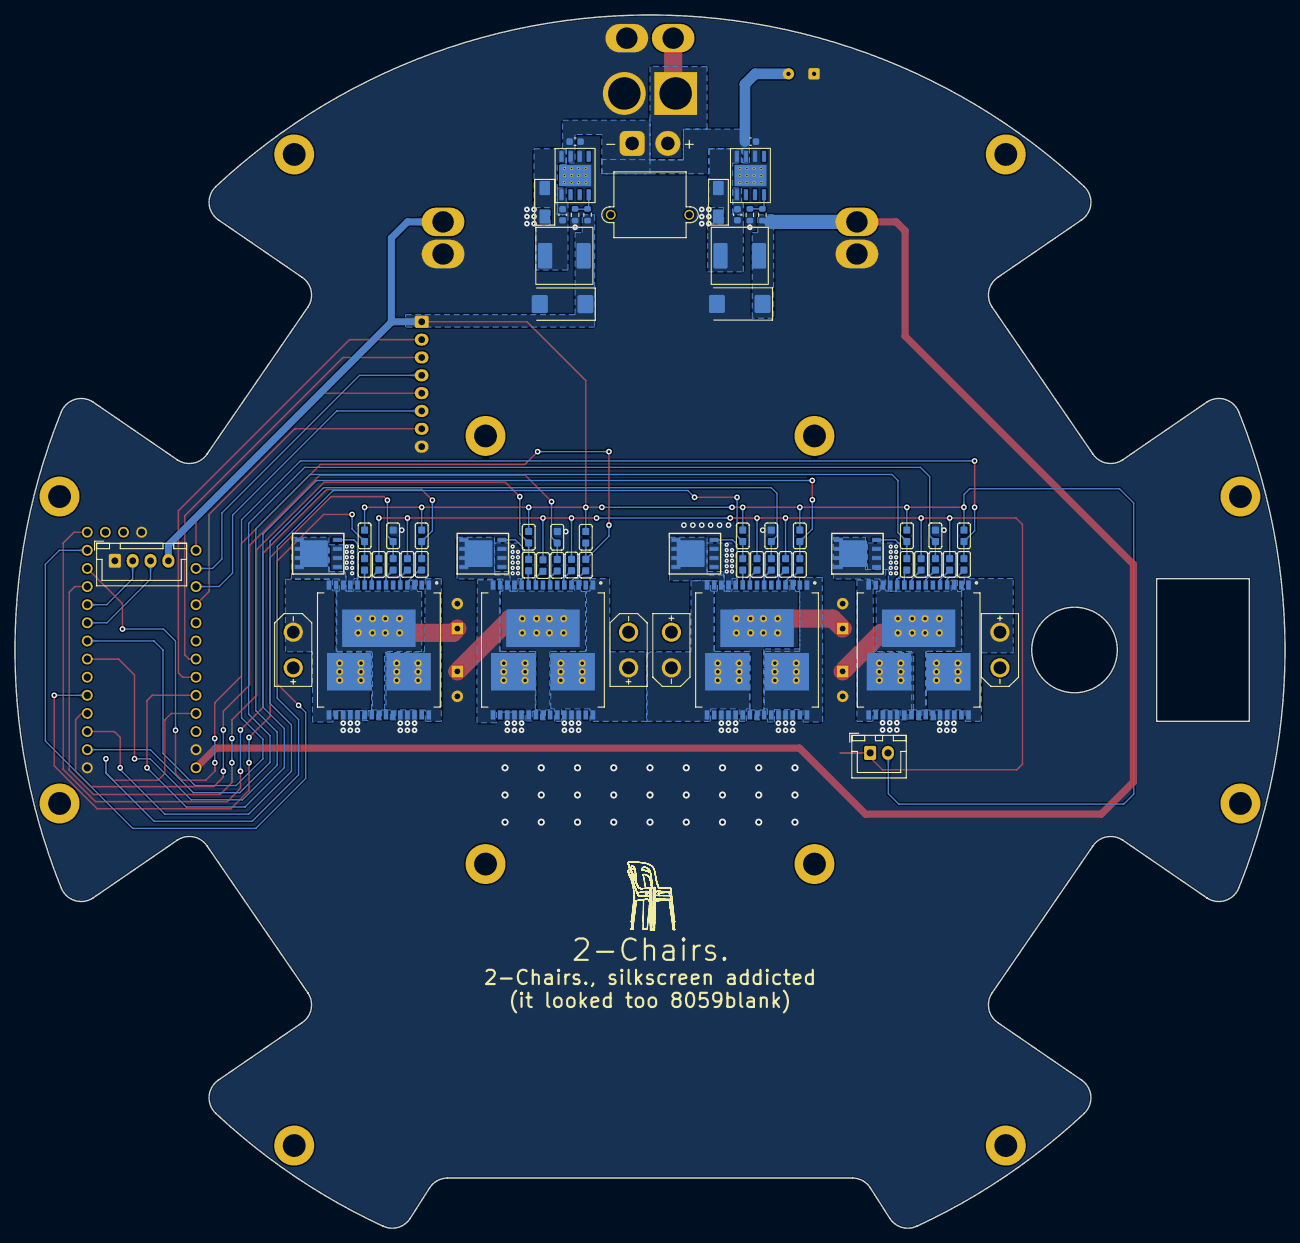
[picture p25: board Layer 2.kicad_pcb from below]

Board: 2 copper layers, 178.0 x 170.0 mm, 87 parts (64 on the bottom side), 68 nets.

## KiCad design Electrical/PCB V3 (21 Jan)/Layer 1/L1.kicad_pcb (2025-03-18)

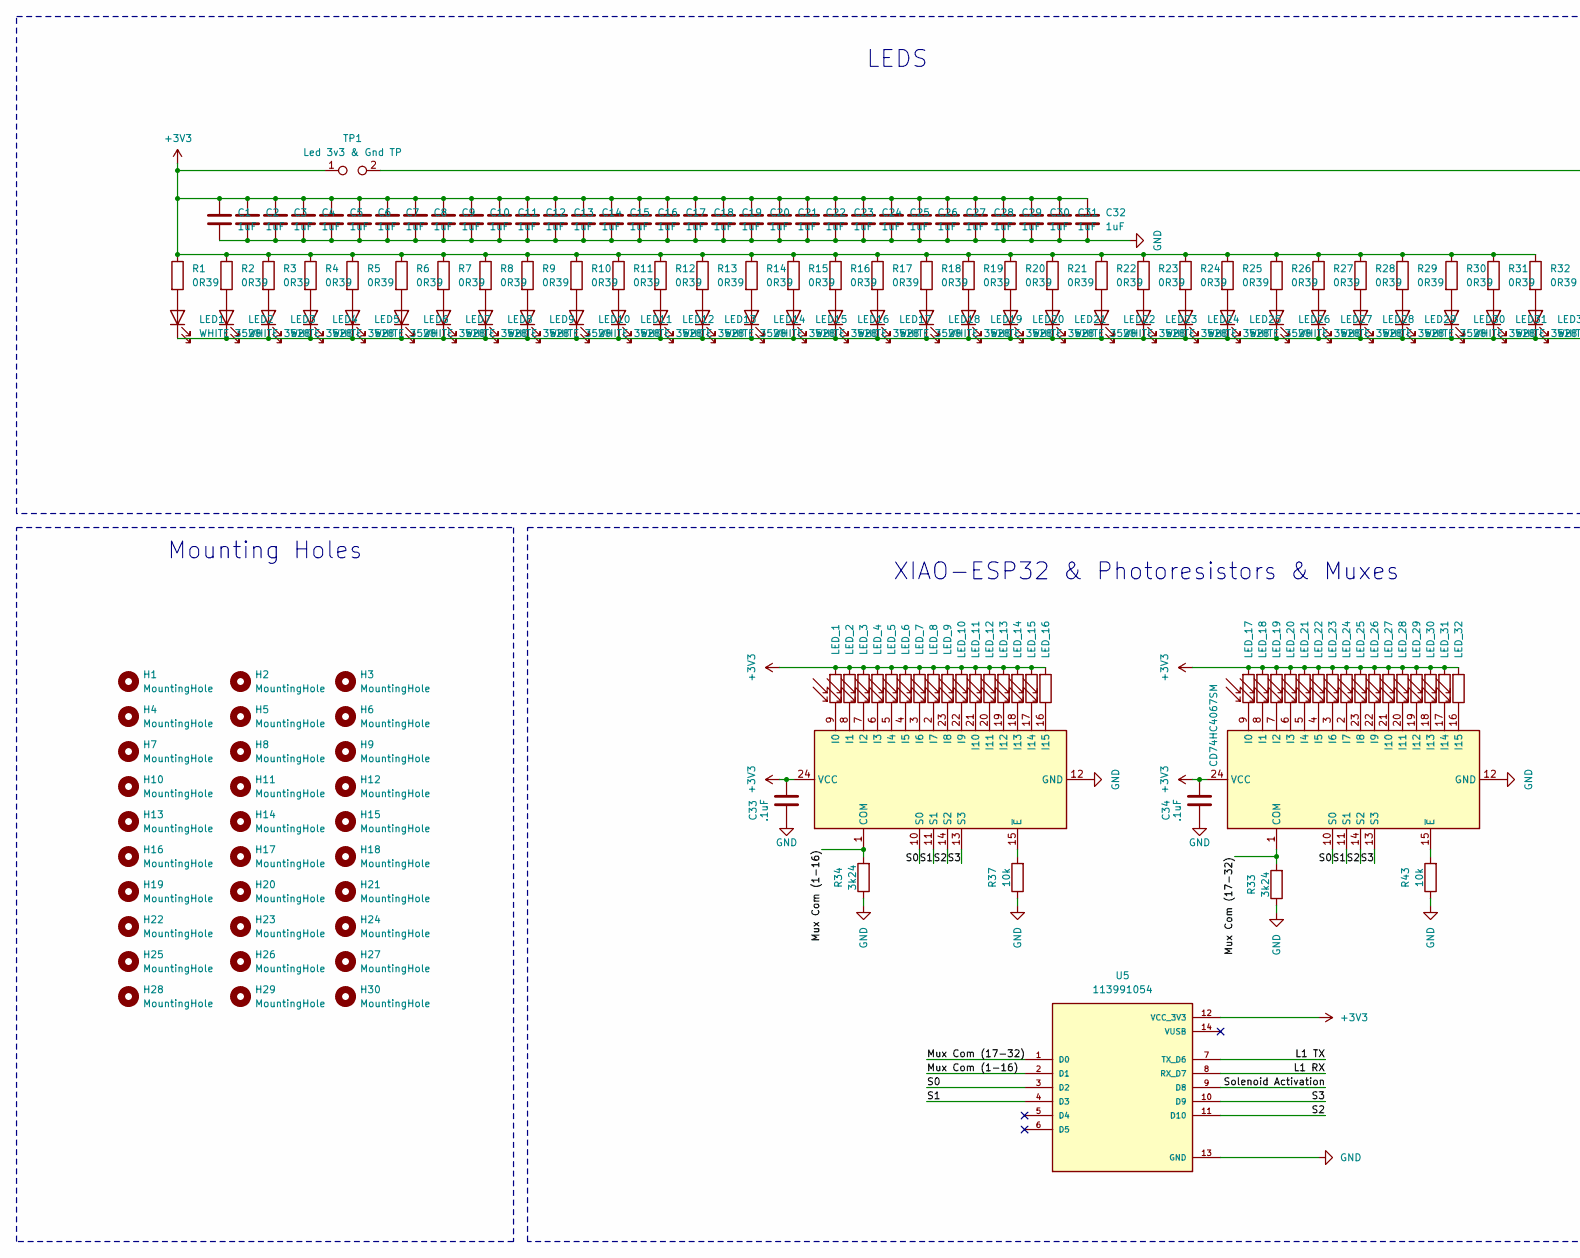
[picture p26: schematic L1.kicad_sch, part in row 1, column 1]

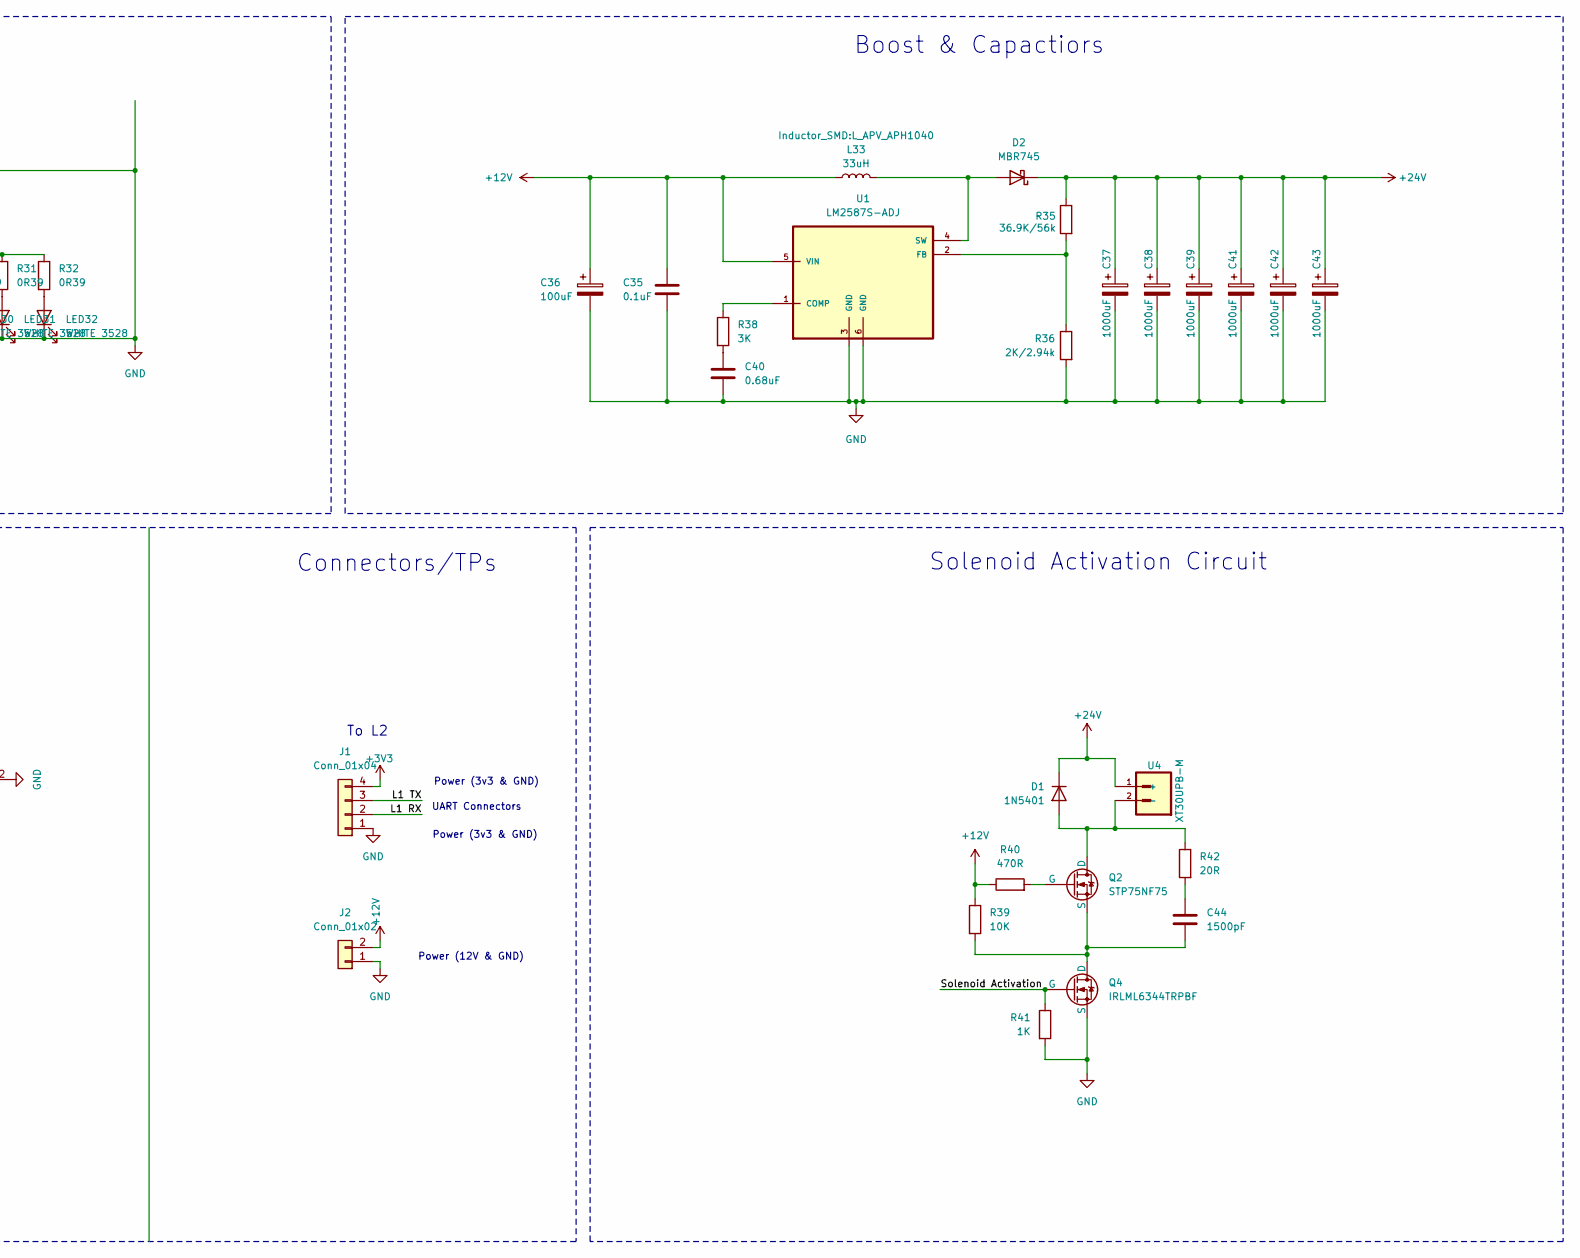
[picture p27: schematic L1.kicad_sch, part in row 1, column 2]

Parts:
C1, C2, C3, C4, C5, C6, C7, C8, C9, C10, C11, C12, C13, C14, C15, C16, C17, C18, C19, C20, C21, C22, C23, C24, C25, C26, C27, C28, C29, C30, C31, C32: 1uF; C_0603_1608Metric
C33, C34: .1uF; C_0603_1608Metric
C35: 0.1uF; C_0603_1608Metric; LCSC C3011705
C36: 100uF; CP_Radial_D8.0mm_P3.50mm; LCSC C249586
C37, C38, C39, C41, C42, C43: 1000uF; CP_Radial_D16.0mm_P7.50mm; LCSC C249586
C40: 0.68uF; C_0603_1608Metric; LCSC C59782
C44: 1500pF; C_0603_1608Metric; LCSC C107060
D1: 1N5401; D_DO-201AD_P15.24mm_Horizontal; LCSC C179506
D2: MBR745; TO-220-2_Vertical
H1, H2, H3, H4, H5, H6, H7, H8, H9, H10, H11, H12, H13, H14, H15, H16, H17, H18, H19, H20, H21, H22, H23, H24, H25, H26, H27, H28, H29, H30: MountingHole; MountingHole_3.2mm_M3_DIN965_Pad
J1: Conn_01x04; JST_EH_B4B-EH-A_1x04_P2.50mm_Vertical
J2: Conn_01x02; AMASS_XT30UPB-M_1x02_P5.0mm_Vertical
L33: 33uH; L_APV_APH1040; LCSC C2875750
LED1, LED2, LED3, LED4, LED5, LED6, LED7, LED8, LED9, LED10, LED11, LED12, LED13, LED14, LED15, LED16, LED17, LED18, LED19, LED20, LED21, LED22, LED23, LED24, LED25, LED26, LED27, LED28, LED29, LED30, LED31, LED32: WHITE 3528; LED_PLCC_2835
LED_1, LED_2, LED_3, LED_4, LED_5, LED_6, LED_7, LED_8, LED_9, LED_10, LED_11, LED_12, LED_13, LED_14, LED_15, LED_16, LED_17, LED_18, LED_19, LED_20, LED_21, LED_22, LED_23, LED_24, LED_25, LED_26, LED_27, LED_28, LED_29, LED_30, LED_31, LED_32: R_Photo; XDCR_ALS-PT19-315C_L177_TR8
Q2: STP75NF75; TO-220-3_Vertical; Mouser Part Number 726-IPD050N10N5ATMA1; LCSC C13678
Q4: IRLML6344TRPBF; SOT95P237X112-3N; Mouser Part Number 942-IRLML6344TRPBF
R1, R2, R3, R4, R5, R6, R7, R8, R9, R10, R11, R12, R13, R14, R15, R16, R17, R18, R19, R20, R21, R22, R23, R24, R25, R26, R27, R28, R29, R30, R31, R32: 0R39; R_0603_1608Metric
R33, R34: 3k24; R_0603_1608Metric
R35: 36.9K/56k; C_0603_1608Metric; LCSC C23082
R36: 2K/2.94k; C_0603_1608Metric; LCSC C22843
R37, R43: 10k; R_0603_1608Metric
R38: 3K; C_0603_1608Metric; LCSC C137748
R39: 10K; R_0603_1608Metric; LCSC C25804
R40: 470R; R_0603_1608Metric; LCSC C21190
R41: 1K; R_0603_1608Metric; LCSC C21190
R42: 20R; R_0603_1608Metric; LCSC C22950
TP1: Led 3v3 & Gnd TP; testpoint_2pad_2-chairs.
U1: LM2587S-ADJ; VREG_TPS79625KTTR
U2, U3: CD74HC4067SM; SOP65P780X200-24N
U4: XT30UPB-M; AMASS_XT30U-M_1x02_P5.0mm_Vertical
U5: 113991054; XiaoSeeedStudioEsp32; PARTREV 23/05/2022

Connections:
+3V3: C1.1, C2.1, C3.1, C4.1, C5.1, C6.1, C7.1, C8.1, C9.1, C10.1, C11.1, C12.1, C13.1, C14.1, C15.1, C16.1, C17.1, C18.1, C19.1, C20.1, C21.1, C22.1, C23.1, C24.1, C25.1, C26.1, C27.1, C28.1, C29.1, C30.1, C31.1, C32.1, C33.2, C34.2, J1.4, LED_1.1, LED_2.1, LED_3.1, LED_4.1, LED_5.1, LED_6.1, LED_7.1, LED_8.1, LED_9.1, LED_10.1, LED_11.1, LED_12.1, LED_13.1, LED_14.1, LED_15.1, LED_16.1, LED_17.1, LED_18.1, LED_19.1, LED_20.1, LED_21.1, LED_22.1, LED_23.1, LED_24.1, LED_25.1, LED_26.1, LED_27.1, LED_28.1, LED_29.1, LED_30.1, LED_31.1, LED_32.1, R1.1, R2.1, R3.1, R4.1, R5.1, R6.1, R7.1, R8.1, R9.1, R10.1, R11.1, R12.1, R13.1, R14.1, R15.1, R16.1, R17.1, R18.1, R19.1, R20.1, R21.1, R22.1, R23.1, R24.1, R25.1, R26.1, R27.1, R28.1, R29.1, R30.1, R31.1, R32.1, TP1.1, U2.24 (VCC), U3.24 (VCC), U5.12 (VCC_3V3)
+12V: C35.1, C36.1, J2.2, L33.1, R39.1, R40.1, U1.5 (VIN)
+24V: C37.1, C38.1, C39.1, C41.1, C42.1, C43.1, D1.1 (K), D2.1 (K), R35.1, U4.1 (+)
/L1 RX: J1.2, U5.8 (RX_D7)
/L1 TX: J1.3, U5.7 (TX_D6)
/Mux Com (1-16): R34.2, U3.1 (COM), U5.2 (D1)
/Mux Com (17-32): R33.2, U2.1 (COM), U5.1 (D0)
/S0: U2.10 (S0), U3.10 (S0), U5.3 (D2)
/S1: U2.11 (S1), U3.11 (S1), U5.4 (D3)
/S2: U2.14 (S2), U3.14 (S2), U5.11 (D10)
/S3: U2.13 (S3), U3.13 (S3), U5.10 (D9)
/Solenoid Activation: Q4.1 (G), R41.1, U5.9 (D8)
GND: C1.2, C2.2, C3.2, C4.2, C5.2, C6.2, C7.2, C8.2, C9.2, C10.2, C11.2, C12.2, C13.2, C14.2, C15.2, C16.2, C17.2, C18.2, C19.2, C20.2, C21.2, C22.2, C23.2, C24.2, C25.2, C26.2, C27.2, C28.2, C29.2, C30.2, C31.2, C32.2, C33.1, C34.1, C35.2, C36.2, C37.2, C38.2, C39.2, C40.2, C41.2, C42.2, C43.2, J1.1, J2.1, LED1.1 (K), LED2.1 (K), LED3.1 (K), LED4.1 (K), LED5.1 (K), LED6.1 (K), LED7.1 (K), LED8.1 (K), LED9.1 (K), LED10.1 (K), LED11.1 (K), LED12.1 (K), LED13.1 (K), LED14.1 (K), LED15.1 (K), LED16.1 (K), LED17.1 (K), LED18.1 (K), LED19.1 (K), LED20.1 (K), LED21.1 (K), LED22.1 (K), LED23.1 (K), LED24.1 (K), LED25.1 (K), LED26.1 (K), LED27.1 (K), LED28.1 (K), LED29.1 (K), LED30.1 (K), LED31.1 (K), LED32.1 (K), Q4.2 (S), R33.1, R34.1, R36.2, R37.1, R41.2, R43.1, TP1.2, U1.3 (GND), U1.6 (GND), U2.12 (GND), U3.12 (GND), U5.13 (GND)
unnamed: C40.1, R38.2
unnamed: C44.1, R42.2
unnamed: D1.2 (A), Q2.2 (D), R42.1, U4.2 (-)
unnamed: D2.2 (A), L33.2, U1.4 (SW)
unnamed: LED1.2 (A), R1.2
unnamed: LED2.2 (A), R2.2
unnamed: LED3.2 (A), R3.2
unnamed: LED4.2 (A), R4.2
unnamed: LED5.2 (A), R5.2
unnamed: LED6.2 (A), R6.2
unnamed: LED7.2 (A), R7.2
unnamed: LED8.2 (A), R8.2
unnamed: LED9.2 (A), R9.2
unnamed: LED10.2 (A), R10.2
unnamed: LED11.2 (A), R11.2
unnamed: LED12.2 (A), R12.2
unnamed: LED13.2 (A), R13.2
unnamed: LED14.2 (A), R14.2
unnamed: LED15.2 (A), R15.2
unnamed: LED16.2 (A), R16.2
unnamed: LED17.2 (A), R17.2
unnamed: LED18.2 (A), R18.2
unnamed: LED19.2 (A), R19.2
unnamed: LED20.2 (A), R20.2
unnamed: LED21.2 (A), R21.2
unnamed: LED22.2 (A), R22.2
unnamed: LED23.2 (A), R23.2
unnamed: LED24.2 (A), R24.2
unnamed: LED25.2 (A), R25.2
unnamed: LED26.2 (A), R26.2
unnamed: LED27.2 (A), R27.2
unnamed: LED28.2 (A), R28.2
unnamed: LED29.2 (A), R29.2
unnamed: LED30.2 (A), R30.2
unnamed: LED31.2 (A), R31.2
unnamed: LED32.2 (A), R32.2
unnamed: Q2.1 (G), R40.2
unnamed: C44.2, Q2.3 (S), Q4.3 (D), R39.2
unnamed: R38.1, U1.1 (COMP)
unnamed: R35.2, R36.1, U1.2 (FB)
unnamed: LED_17.2, U2.9 (I0)
unnamed: LED_18.2, U2.8 (I1)
unnamed: LED_19.2, U2.7 (I2)
unnamed: LED_20.2, U2.6 (I3)
unnamed: LED_21.2, U2.5 (I4)
unnamed: LED_22.2, U2.4 (I5)
unnamed: LED_23.2, U2.3 (I6)
unnamed: LED_24.2, U2.2 (I7)
unnamed: LED_25.2, U2.23 (I8)
unnamed: LED_26.2, U2.22 (I9)
unnamed: LED_27.2, U2.21 (I10)
unnamed: LED_28.2, U2.20 (I11)
unnamed: LED_29.2, U2.19 (I12)
unnamed: LED_30.2, U2.18 (I13)
unnamed: LED_31.2, U2.17 (I14)
unnamed: LED_32.2, U2.16 (I15)
unnamed: R43.2, U2.15 (~E)
unnamed: LED_1.2, U3.9 (I0)
unnamed: LED_2.2, U3.8 (I1)
unnamed: LED_3.2, U3.7 (I2)
unnamed: LED_4.2, U3.6 (I3)
unnamed: LED_5.2, U3.5 (I4)
unnamed: LED_6.2, U3.4 (I5)
unnamed: LED_7.2, U3.3 (I6)
unnamed: LED_8.2, U3.2 (I7)
unnamed: LED_9.2, U3.23 (I8)
unnamed: LED_10.2, U3.22 (I9)
unnamed: LED_11.2, U3.21 (I10)
unnamed: LED_12.2, U3.20 (I11)
unnamed: LED_13.2, U3.19 (I12)
unnamed: LED_14.2, U3.18 (I13)
unnamed: LED_15.2, U3.17 (I14)
unnamed: LED_16.2, U3.16 (I15)
unnamed: R37.2, U3.15 (~E)

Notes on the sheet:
Power (12V & GND)
LEDS
XIAO-ESP32 & Photoresistors & Muxes
Power (3v3 & GND)
To L2
UART Connectors
Boost & Capactiors
Solenoid Activation Circuit
Connectors/TPs
Mounting Holes

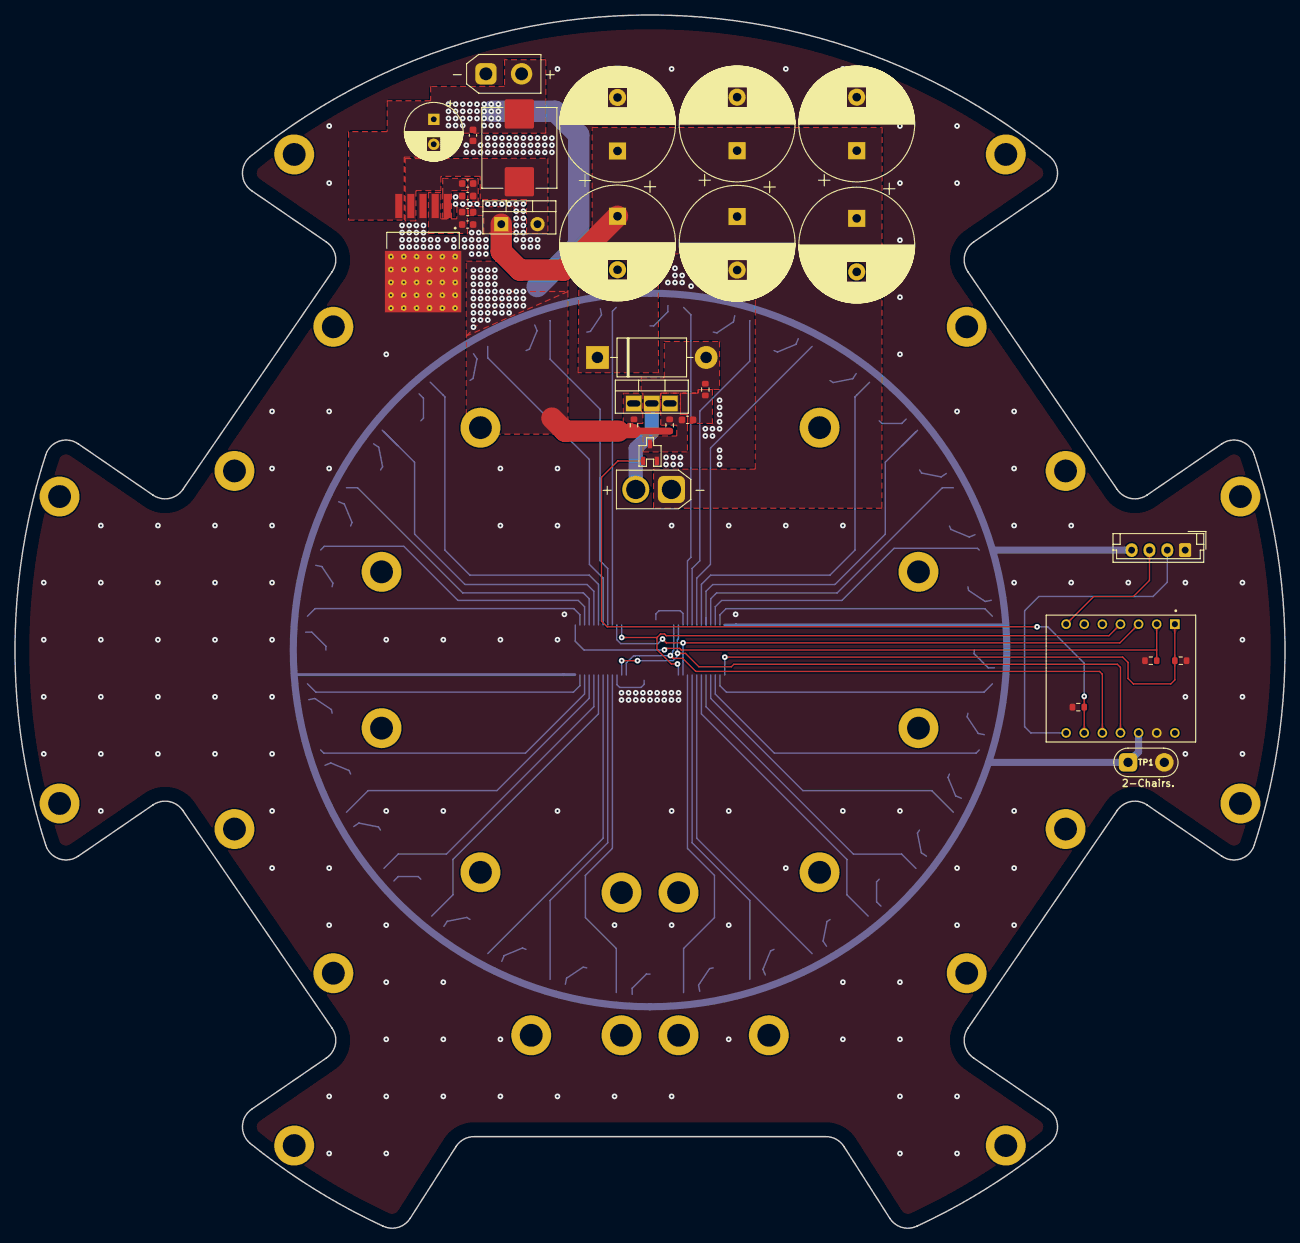
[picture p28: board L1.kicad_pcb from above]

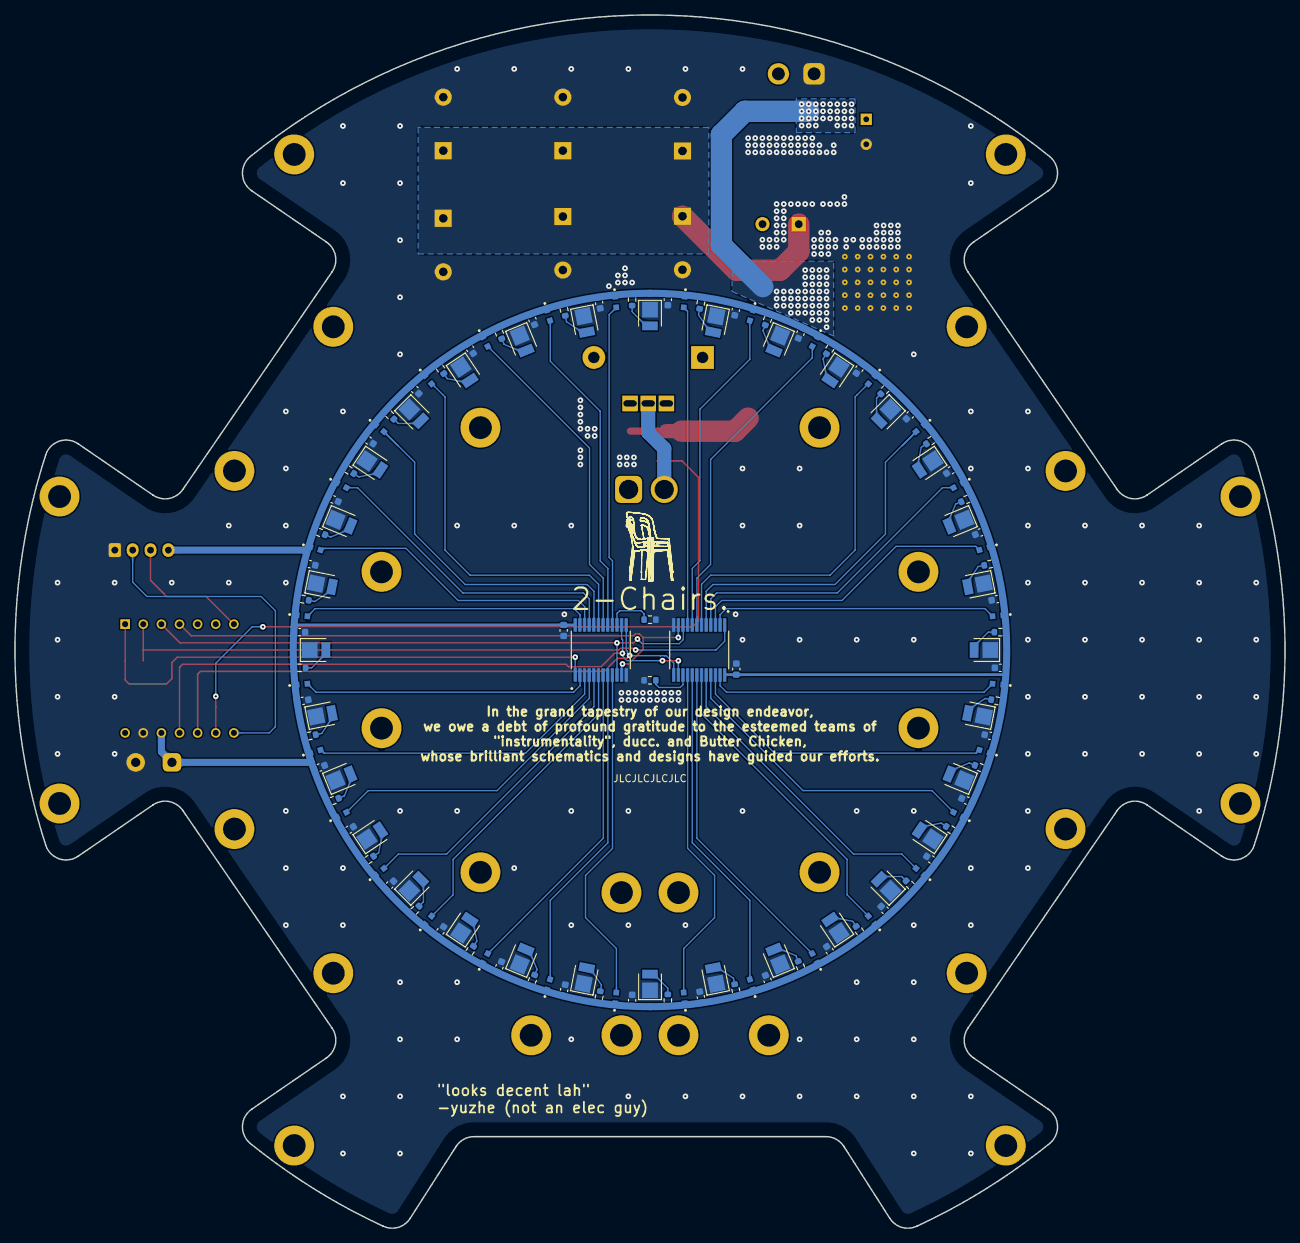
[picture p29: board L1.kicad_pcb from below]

Board: 2 copper layers, 178.0 x 170.0 mm, 194 parts (134 on the bottom side), 87 nets.

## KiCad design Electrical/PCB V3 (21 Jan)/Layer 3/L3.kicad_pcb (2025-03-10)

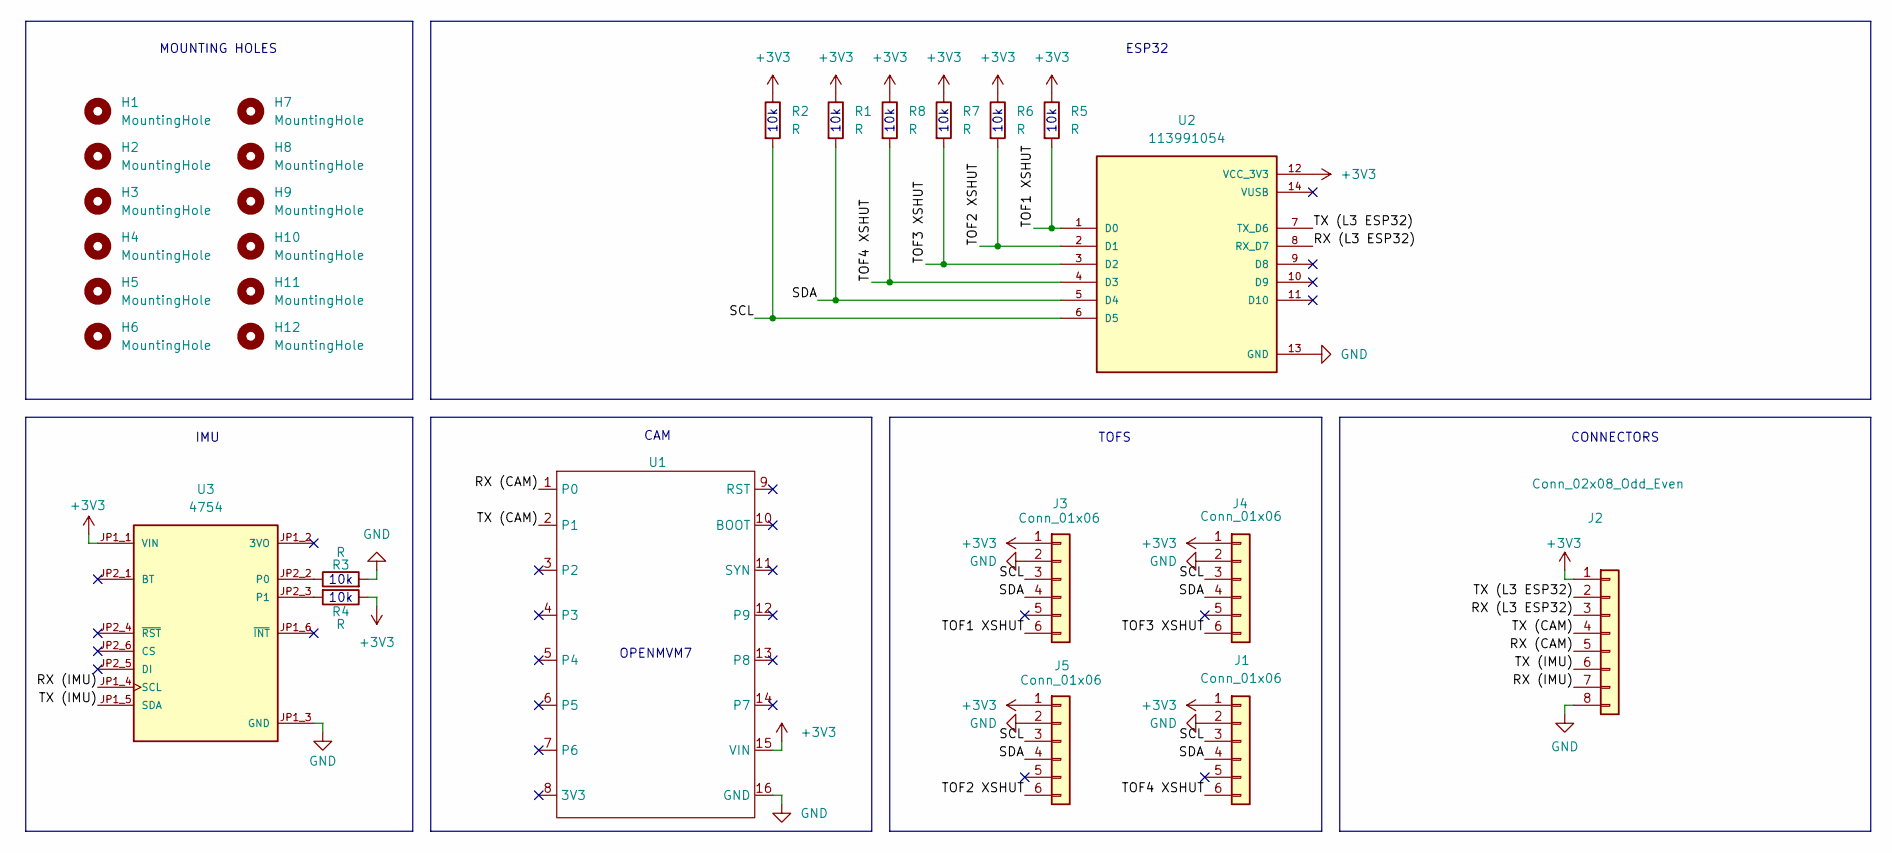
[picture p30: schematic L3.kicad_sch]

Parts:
H1, H2, H3, H4, H5, H6, H7, H8, H9, H10, H11, H12: MountingHole; MountingHole_3.2mm_M3_Pad_Via
J1, J3, J4, J5: Conn_01x06; PinHeader_1x06_P2.54mm_Vertical
J2: Conn_02x08_Odd_Even; JST_XH_B8B-XH-A_1x08_P2.50mm_Vertical
R1, R2, R3, R4, R5, R6, R7, R8: R; R_0603_1608Metric_Pad0.98x0.95mm_HandSolder
U1: OPENMV_M7
U2: 113991054; MODULE_113991054; PARTREV 23/05/2022
U3: 4754; MODULE_4754; PARTREV 2021-03-16

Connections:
+3V3: J1.1, J2.1, J3.1, J4.1, J5.1, R1.1, R2.1, R4.1, R5.1, R6.1, R7.1, R8.1, U1.15 (VIN), U2.12 (VCC_3V3), U3.JP1_1 (VIN)
/RX (CAM): J2.5, U1.1 (P0)
/RX (IMU): J2.7, U3.JP1_4 (SCL)
/RX (L3 ESP32): J2.3, U2.8 (RX_D7)
/SCL: J1.3, J3.3, J4.3, J5.3, R2.2, U2.6 (D5)
/SDA: J1.4, J3.4, J4.4, J5.4, R1.2, U2.5 (D4)
/TOF1 XSHUT: J3.6, R5.2, U2.1 (D0)
/TOF2 XSHUT: J5.6, R6.2, U2.2 (D1)
/TOF3 XSHUT: J4.6, R7.2, U2.3 (D2)
/TOF4 XSHUT: J1.6, R8.2, U2.4 (D3)
/TX (CAM): J2.4, U1.2 (P1)
/TX (IMU): J2.6, U3.JP1_5 (SDA)
/TX (L3 ESP32): J2.2, U2.7 (TX_D6)
GND: J1.2, J2.8, J3.2, J4.2, J5.2, R3.2, U1.16 (GND), U2.13 (GND), U3.JP1_3 (GND)
unnamed: R3.1, U3.JP2_2 (P0)
unnamed: R4.2, U3.JP2_3 (P1)

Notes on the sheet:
IMU
10k
TOFS
ESP32
CONNECTORS
MOUNTING HOLES
CAM
OPENMVM7

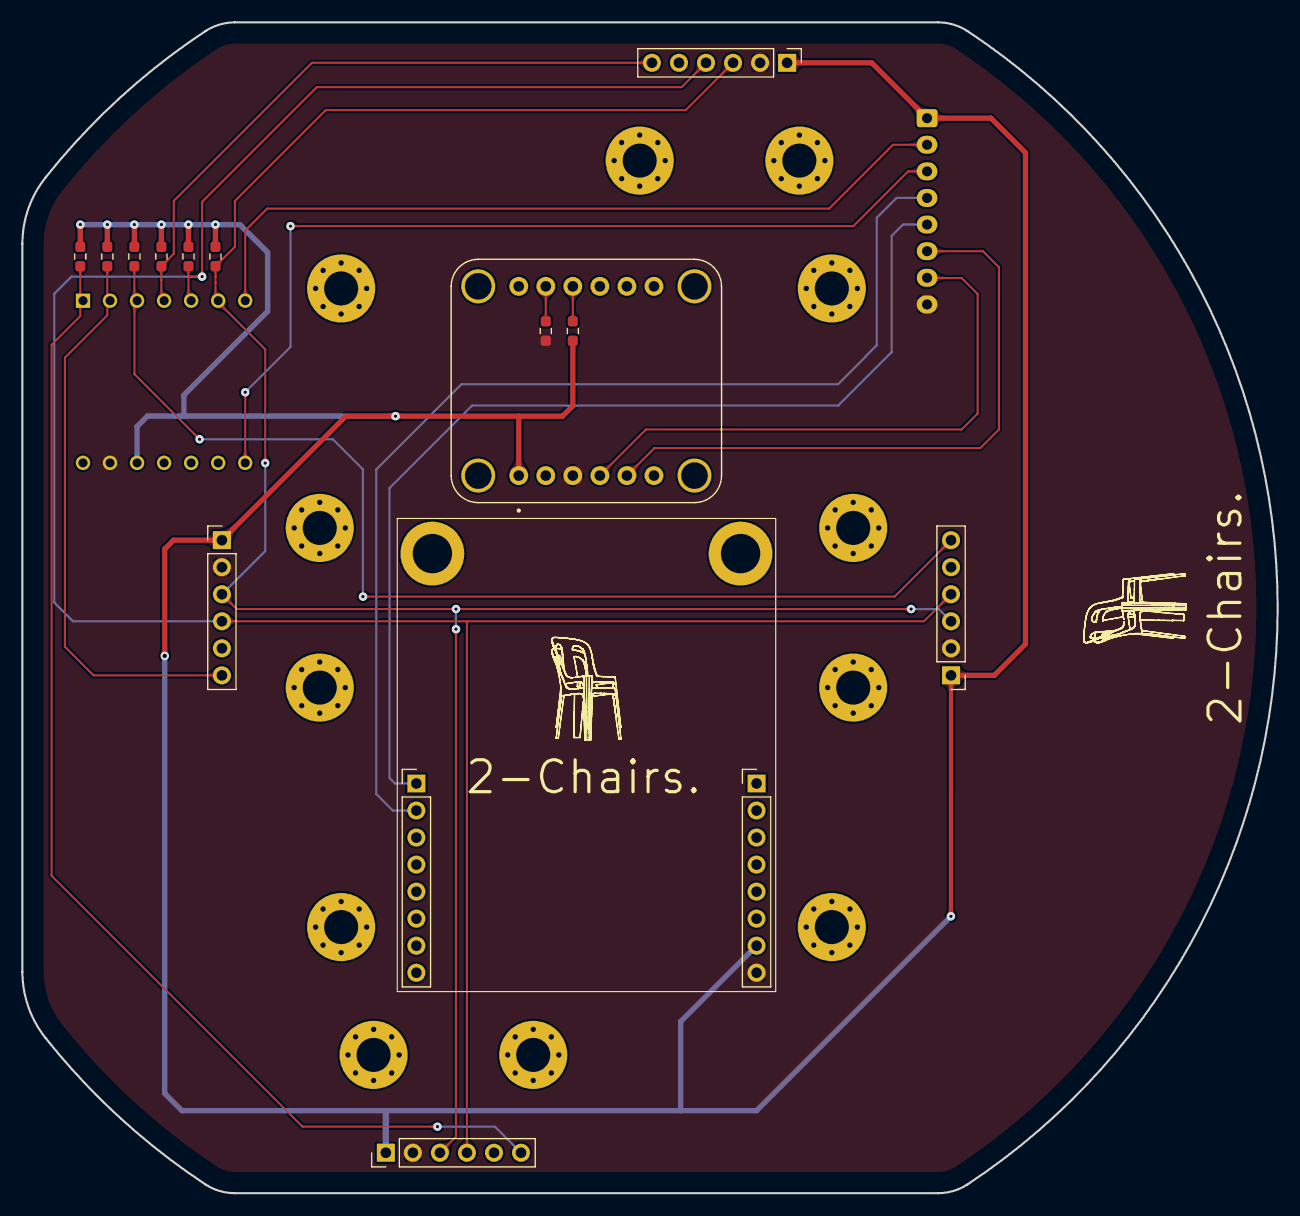
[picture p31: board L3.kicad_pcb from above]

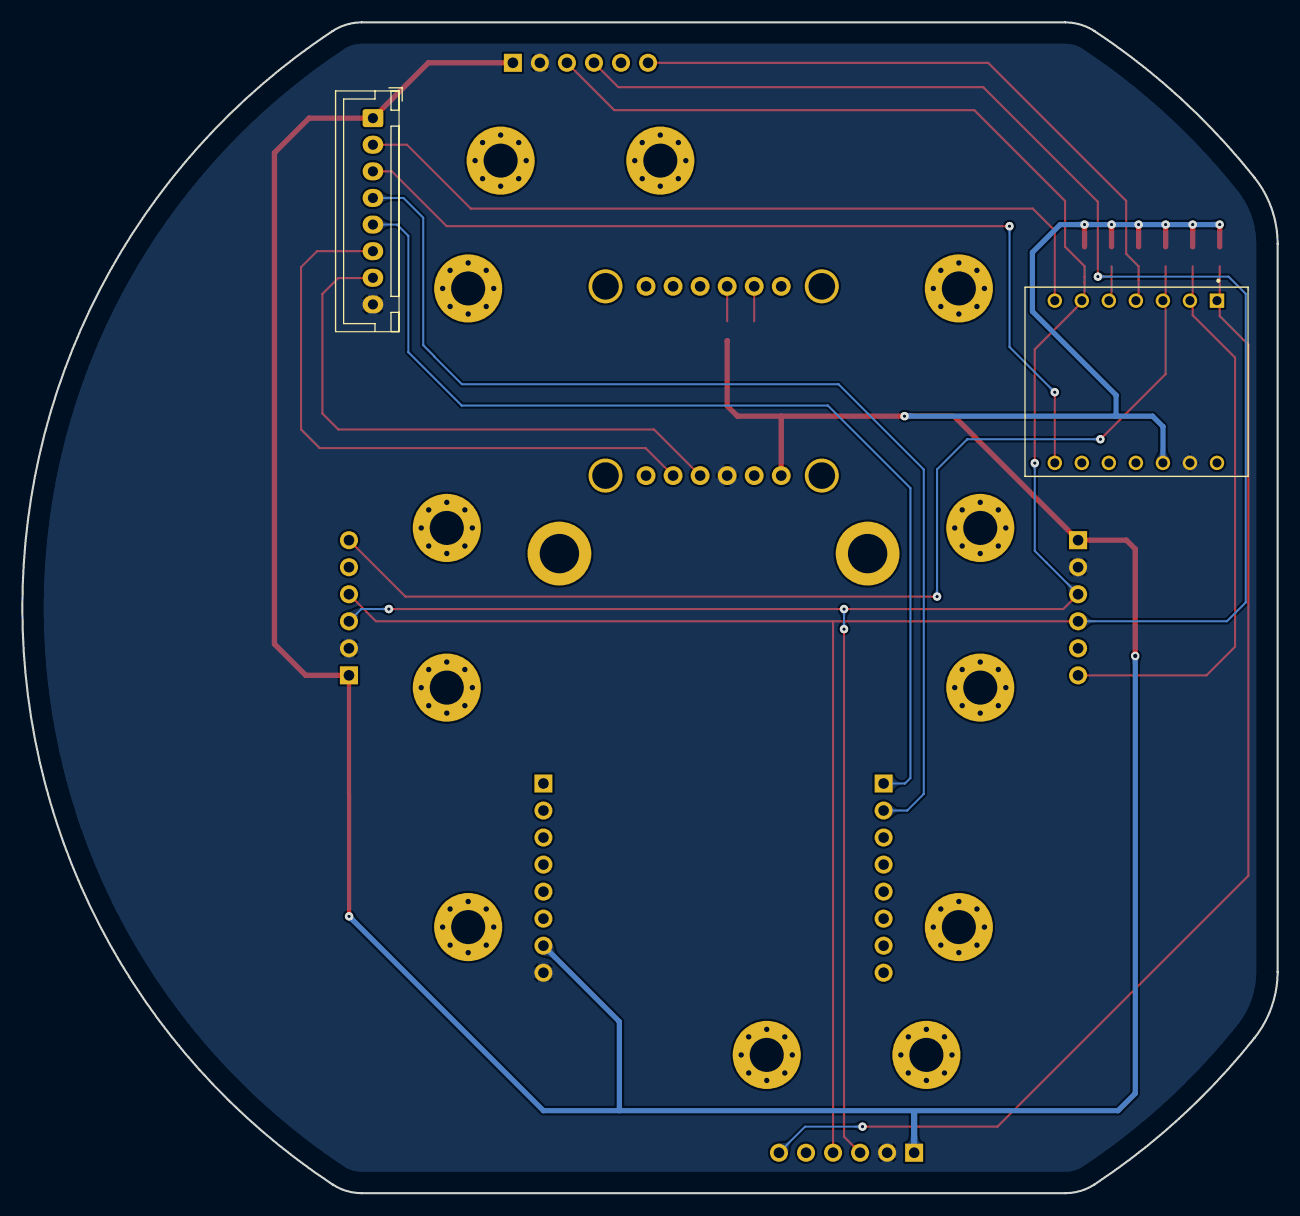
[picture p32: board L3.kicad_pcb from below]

Board: 2 copper layers, 117.9 x 110.0 mm, 28 parts (2 on the bottom side), 16 nets.

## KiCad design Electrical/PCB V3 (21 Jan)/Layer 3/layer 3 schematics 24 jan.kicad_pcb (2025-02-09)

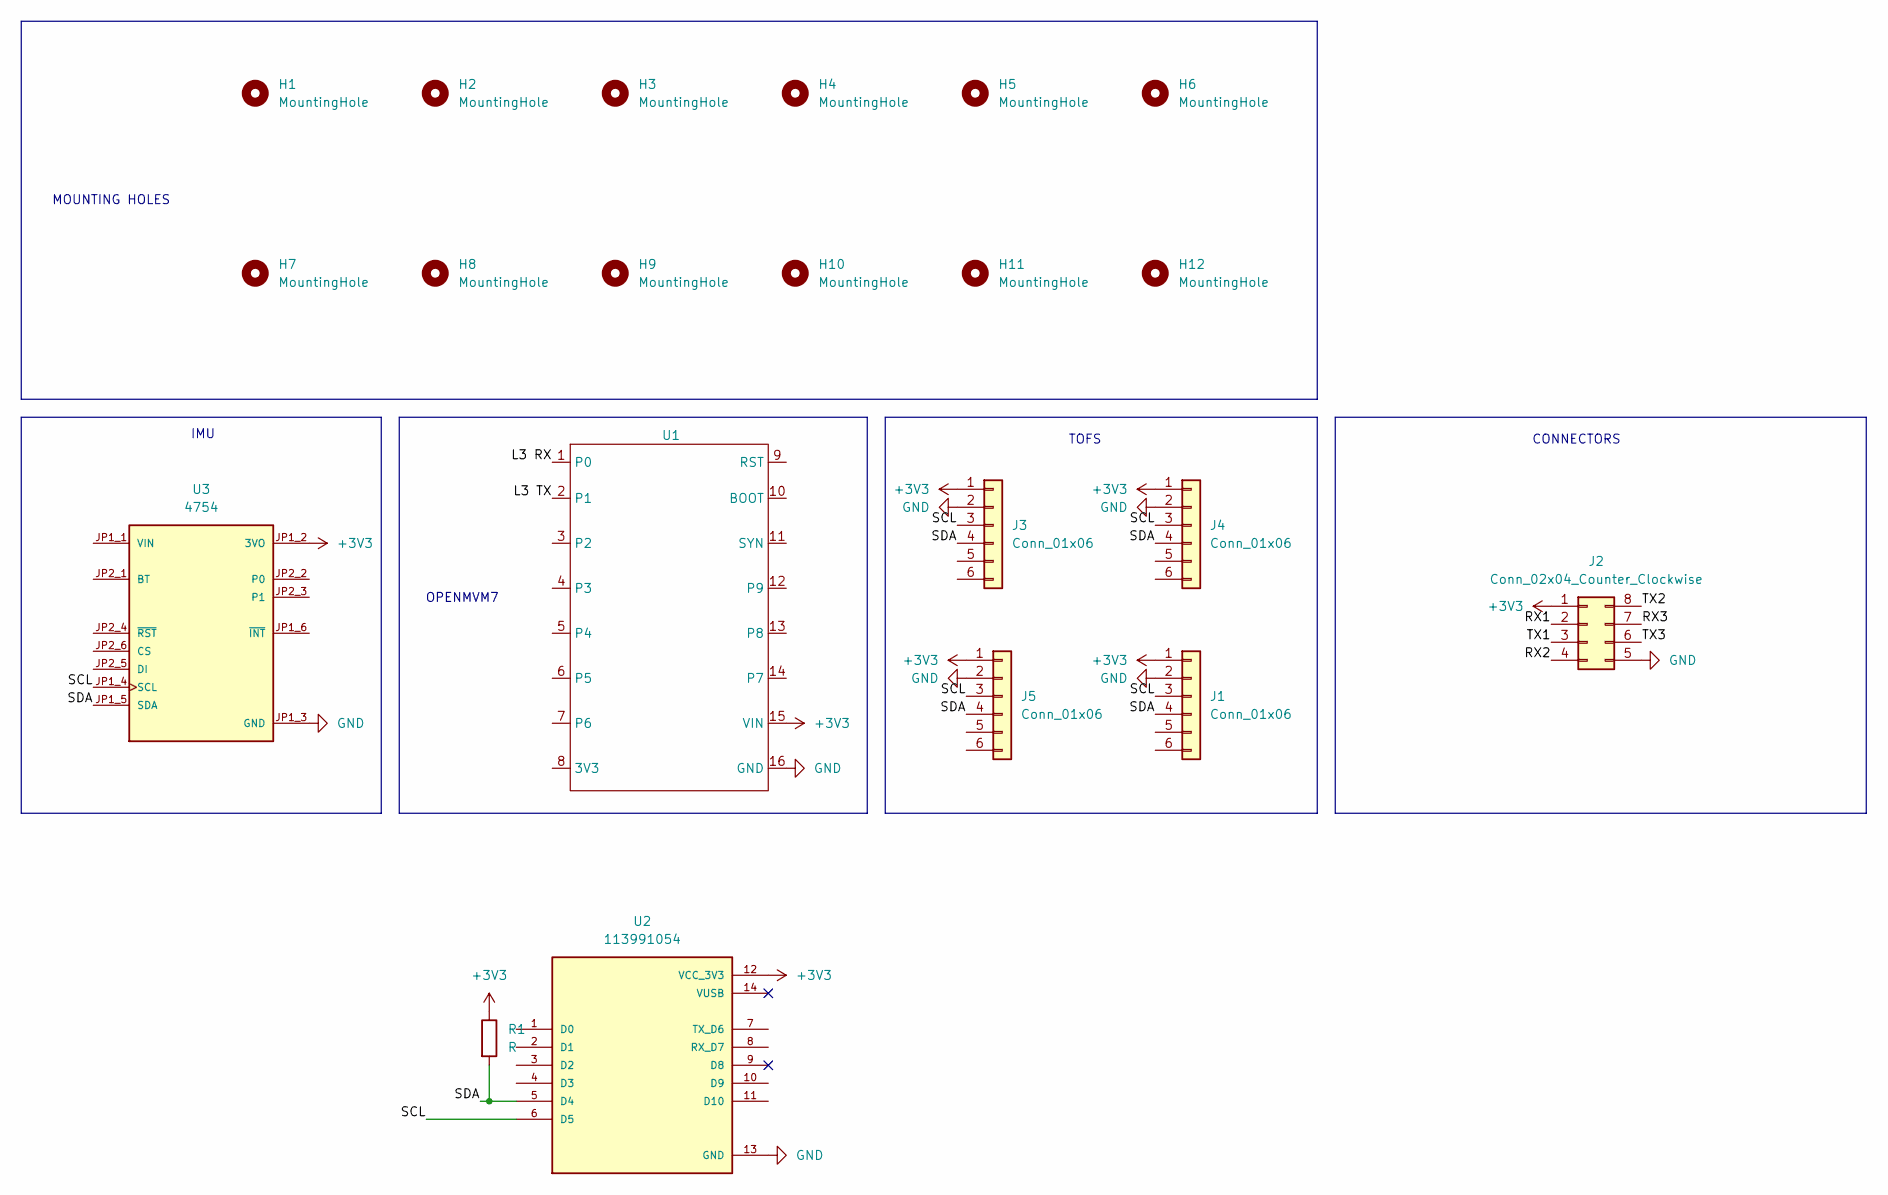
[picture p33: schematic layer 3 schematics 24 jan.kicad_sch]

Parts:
H1, H2, H3, H4, H5, H6, H7, H8, H9, H10, H11, H12: MountingHole; MountingHole_3.2mm_M3_Pad_Via
J1, J3, J4, J5: Conn_01x06; PinHeader_1x06_P2.54mm_Vertical
J2: Conn_02x04_Counter_Clockwise; JST_PHD_B8B-PHDSS_2x04_P2.00mm_Vertical
R1: R
U1: OPENMV_M7
U2: 113991054; XiaoSeeedStudioEsp32; PARTREV 23/05/2022
U3: 4754; MODULE_4754; PARTREV 2021-03-16

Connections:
+3V3: J1.1, J2.1, J3.1, J4.1, J5.1, R1.1, U1.15 (VIN), U2.12 (VCC_3V3), U3.JP1_2 (3VO)
/L3 RX: U1.1 (P0)
/L3 TX: U1.2 (P1)
/RX1: J2.2
/RX2: J2.4
/RX3: J2.7
/SCL: J1.3, J3.3, J4.3, J5.3, U2.6 (D5), U3.JP1_4 (SCL)
/SDA: J1.4, J3.4, J4.4, J5.4, R1.2, U2.5 (D4), U3.JP1_5 (SDA)
/TX1: J2.3
/TX2: J2.8
/TX3: J2.6
GND: J1.2, J2.5, J3.2, J4.2, J5.2, U1.16 (GND), U2.13 (GND), U3.JP1_3 (GND)

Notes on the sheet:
IMU
TOFS
CONNECTORS
MOUNTING HOLES
OPENMVM7

Board: 2 copper layers, 19 parts (0 on the bottom side), 4 nets, no tracks yet.

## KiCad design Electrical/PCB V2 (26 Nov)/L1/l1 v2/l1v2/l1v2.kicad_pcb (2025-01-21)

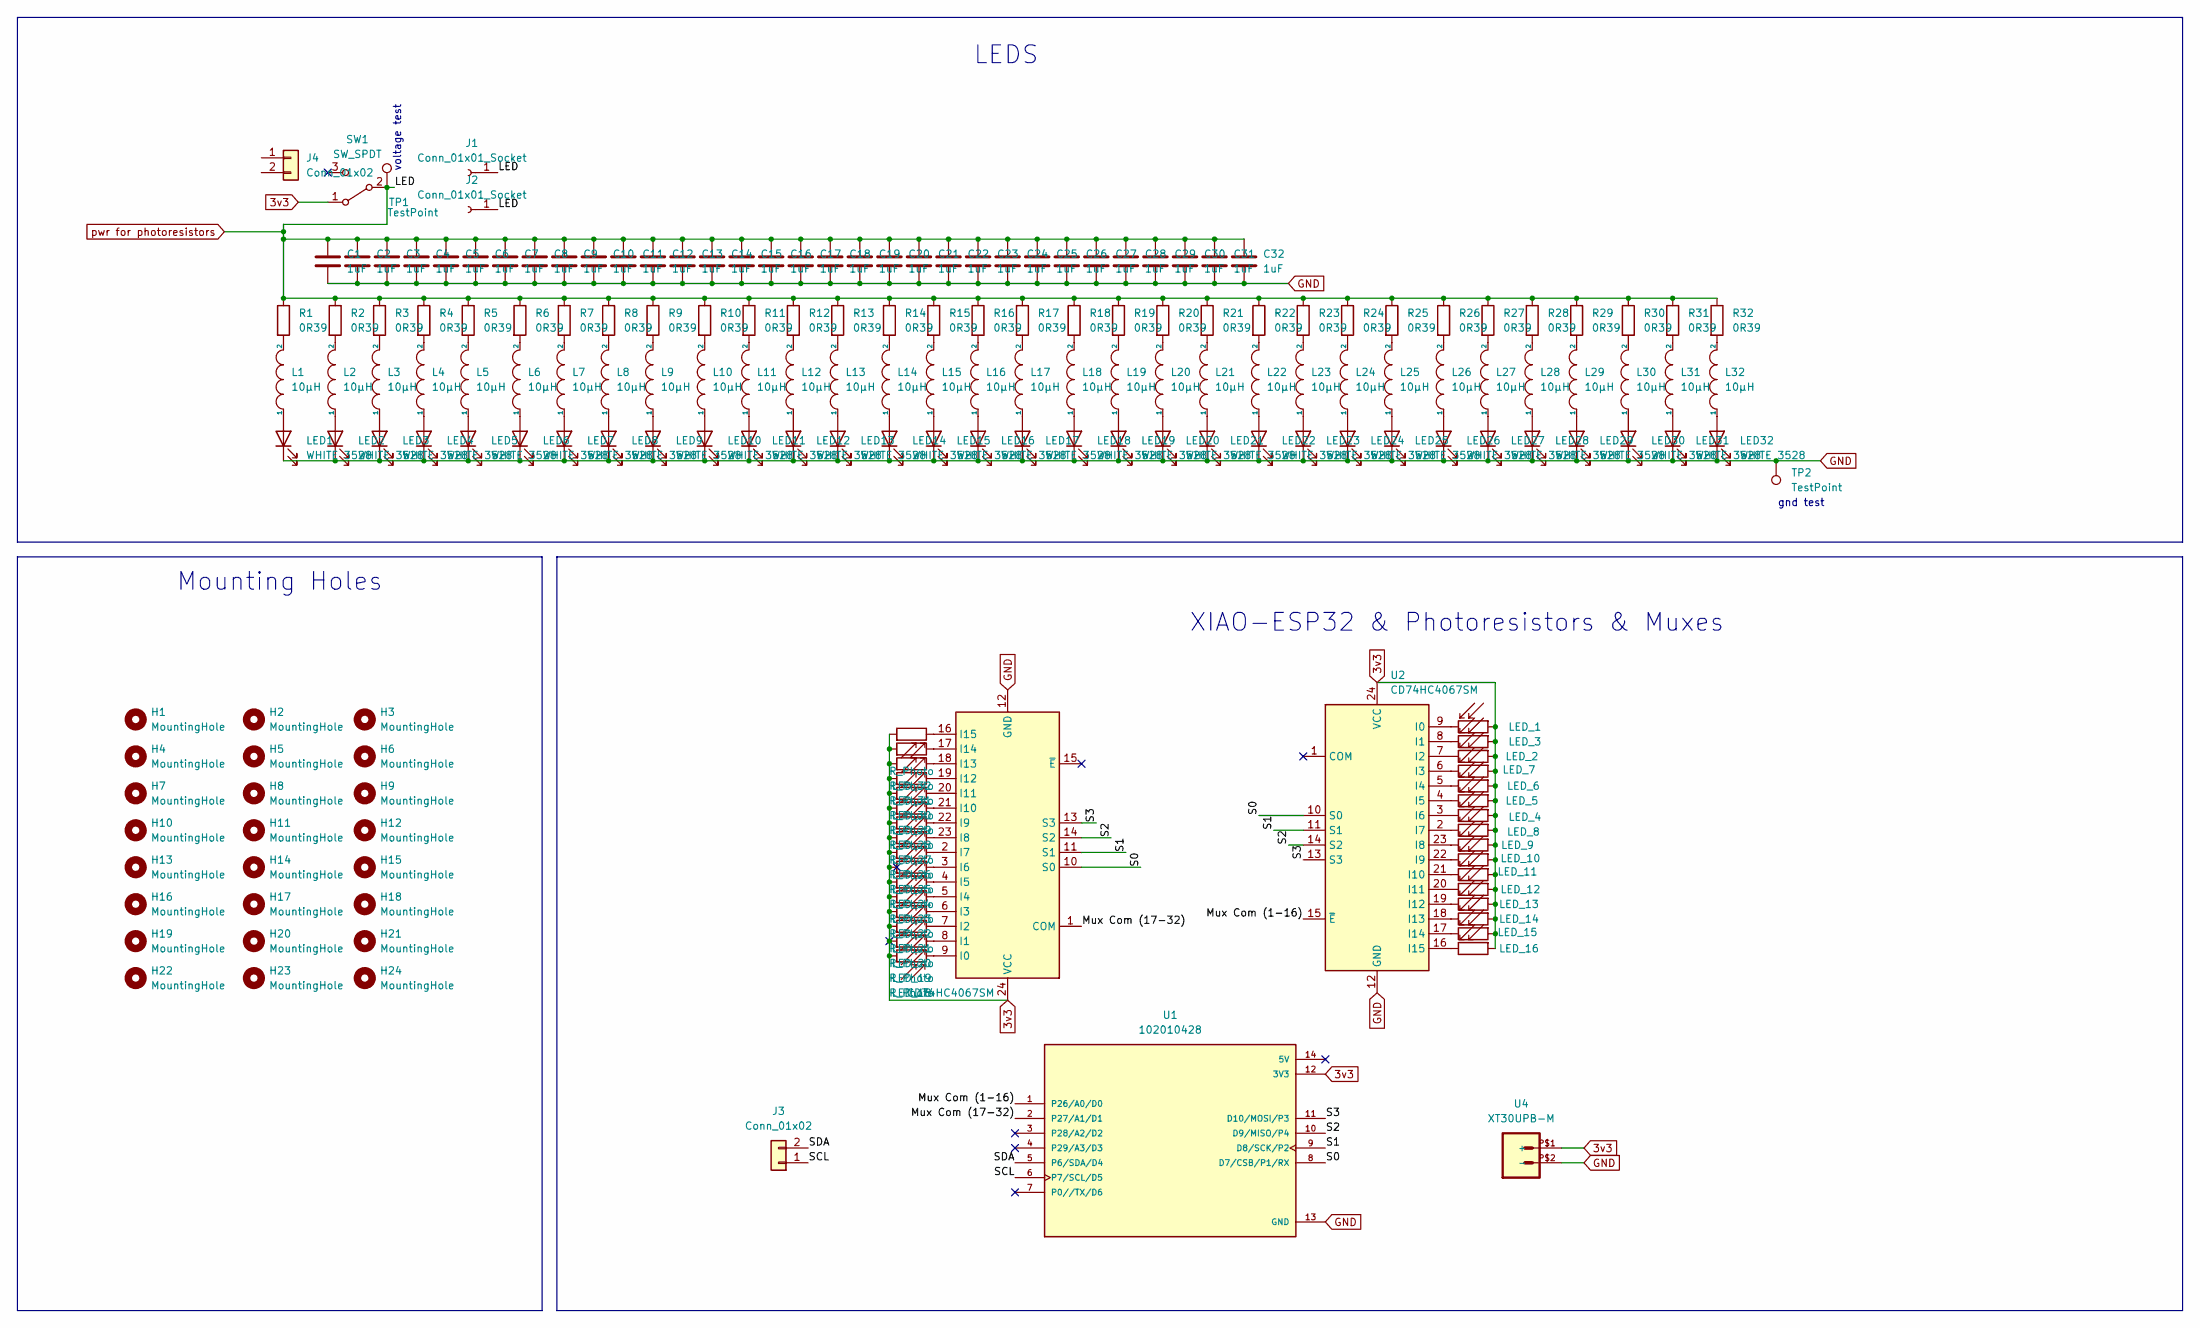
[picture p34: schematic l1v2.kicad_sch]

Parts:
C1, C2, C3, C4, C5, C6, C7, C8, C9, C10, C11, C12, C13, C14, C15, C16, C17, C18, C19, C20, C21, C22, C23, C24, C25, C26, C27, C28, C29, C30, C31, C32: 1uF; C_0603_1608Metric
H1, H2, H3, H4, H5, H6, H7, H8, H9, H10, H11, H12, H13, H14, H15, H16, H17, H18, H19, H20, H21, H22, H23, H24: MountingHole; MountingHole_3.2mm_M3_DIN965_Pad
J1: Conn_01x01_Socket; SolderWirePad_1x01_SMD_1x2mm
J2: Conn_01x01_Socket; SolderWire-0.5sqmm_1x01_D0.9mm_OD2.1mm
J3: Conn_01x02; PinHeader_1x02_P1.00mm_Horizontal
J4: Conn_01x02
L1, L2, L3, L4, L5, L6, L7, L8, L9, L10, L11, L12, L13, L14, L15, L16, L17, L18, L19, L20, L21, L22, L23, L24, L25, L26, L27, L28, L29, L30, L31, L32: 10µH; L_0805_2012Metric
LED1, LED2, LED3, LED4, LED5, LED6, LED7, LED8, LED9, LED10, LED11, LED12, LED13, LED14, LED15, LED16, LED17, LED18, LED19, LED20, LED21, LED22, LED23, LED24, LED25, LED26, LED27, LED28, LED29, LED30, LED31, LED32: WHITE 3528; LED_PLCC_2835
LED_1, LED_2, LED_3, LED_4, LED_5, LED_6, LED_7, LED_8, LED_9, LED_10, LED_11, LED_12, LED_13, LED_14, LED_15, LED_16, LED_17, LED_18, LED_19, LED_20, LED_21, LED_22, LED_23, LED_24, LED_25, LED_26, LED_27, LED_28, LED_29, LED_30, LED_31, LED_32: R_Photo; XDCR_ALS-PT19-315C_L177_TR8
R1, R2, R3, R4, R5, R6, R7, R8, R9, R10, R11, R12, R13, R14, R15, R16, R17, R18, R19, R20, R21, R22, R23, R24, R25, R26, R27, R28, R29, R30, R31, R32: 0R39; R_0603_1608Metric
SW1: SW_SPDT; Nidec_Copal_CAS-120A
TP1, TP2: TestPoint; TestPoint_2Pads_Pitch2.54mm_Drill0.8mm
U1: 102010428; MCU_Seeed_ESP32C3; PARTREV 1.3
U2, U3: CD74HC4067SM; SOP65P780X200-24N
U4: XT30UPB-M

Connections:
3v3: LED_1.1, LED_2.1, LED_3.1, LED_4.1, LED_5.1, LED_6.1, LED_7.1, LED_8.1, LED_9.1, LED_10.1, LED_11.1, LED_12.1, LED_13.1, LED_14.1, LED_15.1, LED_16.1, LED_17.1, LED_18.1, LED_19.1, LED_20.1, LED_21.1, LED_22.1, LED_23.1, LED_24.1, LED_25.1, LED_26.1, LED_27.1, LED_28.1, LED_29.1, LED_30.1, LED_31.1, LED_32.1, SW1.1 (A), U1.12 (3V3), U2.24 (VCC), U3.24 (VCC), U4.P$1 (+)
/Mux Com (1-16): U1.1 (P26/A0/D0), U2.15 (~E)
/Mux Com (17-32): U1.2 (P27/A1/D1), U3.1 (COM)
/S0: U1.8 (D7/CSB/P1/RX), U2.10 (S0), U3.10 (S0)
/S1: U1.9 (D8/SCK/P2), U2.11 (S1), U3.11 (S1)
/S2: U1.10 (D9/MISO/P4), U2.14 (S2), U3.14 (S2)
/S3: U1.11 (D10/MOSI/P3), U2.13 (S3), U3.13 (S3)
/SCL: J3.1, U1.6 (P7/SCL/D5)
/SDA: J3.2, U1.5 (P6/SDA/D4)
GND: C1.2, C2.2, C3.2, C4.2, C5.2, C6.2, C7.2, C8.2, C9.2, C10.2, C11.2, C12.2, C13.2, C14.2, C15.2, C16.2, C17.2, C18.2, C19.2, C20.2, C21.2, C22.2, C23.2, C24.2, C25.2, C26.2, C27.2, C28.2, C29.2, C30.2, C31.2, C32.2, LED1.1 (K), LED2.1 (K), LED3.1 (K), LED4.1 (K), LED5.1 (K), LED6.1 (K), LED7.1 (K), LED8.1 (K), LED9.1 (K), LED10.1 (K), LED11.1 (K), LED12.1 (K), LED13.1 (K), LED14.1 (K), LED15.1 (K), LED16.1 (K), LED17.1 (K), LED18.1 (K), LED19.1 (K), LED20.1 (K), LED21.1 (K), LED22.1 (K), LED23.1 (K), LED24.1 (K), LED25.1 (K), LED26.1 (K), LED27.1 (K), LED28.1 (K), LED29.1 (K), LED30.1 (K), LED31.1 (K), LED32.1 (K), TP2.1, U1.13 (GND), U2.12 (GND), U3.12 (GND), U4.P$2 (-)
unnamed: L1.2, R1.2
unnamed: L2.2, R2.2
unnamed: L3.2, R3.2
unnamed: L4.2, R4.2
unnamed: L5.2, R5.2
unnamed: L6.2, R6.2
unnamed: L7.2, R7.2
unnamed: L8.2, R8.2
unnamed: L9.2, R9.2
unnamed: L10.2, R10.2
unnamed: L11.2, R11.2
unnamed: L12.2, R12.2
unnamed: L13.2, R13.2
unnamed: L14.2, R14.2
unnamed: L15.2, R15.2
unnamed: L16.2, R16.2
unnamed: L17.2, R17.2
unnamed: L18.2, R18.2
unnamed: L19.2, R19.2
unnamed: L20.2, R20.2
unnamed: L21.2, R21.2
unnamed: L22.2, R22.2
unnamed: L23.2, R23.2
unnamed: L24.2, R24.2
unnamed: L25.2, R25.2
unnamed: L26.2, R26.2
unnamed: L27.2, R27.2
unnamed: L28.2, R28.2
unnamed: L29.2, R29.2
unnamed: L30.2, R30.2
unnamed: L31.2, R31.2
unnamed: L32.2, R32.2
unnamed: L1.1, LED1.2 (A)
unnamed: L2.1, LED2.2 (A)
unnamed: L3.1, LED3.2 (A)
unnamed: L4.1, LED4.2 (A)
unnamed: L5.1, LED5.2 (A)
unnamed: L6.1, LED6.2 (A)
unnamed: L7.1, LED7.2 (A)
unnamed: L8.1, LED8.2 (A)
unnamed: L9.1, LED9.2 (A)
unnamed: L10.1, LED10.2 (A)
unnamed: L11.1, LED11.2 (A)
unnamed: L12.1, LED12.2 (A)
unnamed: L13.1, LED13.2 (A)
unnamed: L14.1, LED14.2 (A)
unnamed: L15.1, LED15.2 (A)
unnamed: L16.1, LED16.2 (A)
unnamed: L17.1, LED17.2 (A)
unnamed: L18.1, LED18.2 (A)
unnamed: L19.1, LED19.2 (A)
unnamed: L20.1, LED20.2 (A)
unnamed: L21.1, LED21.2 (A)
unnamed: L22.1, LED22.2 (A)
unnamed: L23.1, LED23.2 (A)
unnamed: L24.1, LED24.2 (A)
unnamed: L25.1, LED25.2 (A)
unnamed: L26.1, LED26.2 (A)
unnamed: L27.1, LED27.2 (A)
unnamed: L28.1, LED28.2 (A)
unnamed: L29.1, LED29.2 (A)
unnamed: L30.1, LED30.2 (A)
unnamed: L31.1, LED31.2 (A)
unnamed: L32.1, LED32.2 (A)
unnamed: LED_1.2, U2.9 (I0)
unnamed: LED_3.2, U2.8 (I1)
unnamed: LED_2.2, U2.7 (I2)
unnamed: LED_7.2, U2.6 (I3)
unnamed: LED_6.2, U2.5 (I4)
unnamed: LED_5.2, U2.4 (I5)
unnamed: LED_4.2, U2.3 (I6)
unnamed: LED_8.2, U2.2 (I7)
unnamed: LED_9.2, U2.23 (I8)
unnamed: LED_10.2, U2.22 (I9)
unnamed: LED_11.2, U2.21 (I10)
unnamed: LED_12.2, U2.20 (I11)
unnamed: LED_13.2, U2.19 (I12)
unnamed: LED_14.2, U2.18 (I13)
unnamed: LED_15.2, U2.17 (I14)
unnamed: LED_16.2, U2.16 (I15)
unnamed: LED_17.2, U3.9 (I0)
unnamed: LED_18.2, U3.8 (I1)
unnamed: LED_19.2, U3.7 (I2)
unnamed: LED_20.2, U3.6 (I3)
unnamed: LED_21.2, U3.5 (I4)
unnamed: LED_22.2, U3.4 (I5)
unnamed: LED_23.2, U3.3 (I6)
unnamed: LED_24.2, U3.2 (I7)
unnamed: LED_25.2, U3.23 (I8)
unnamed: LED_26.2, U3.22 (I9)
unnamed: LED_27.2, U3.21 (I10)
unnamed: LED_28.2, U3.20 (I11)
unnamed: LED_29.2, U3.19 (I12)
unnamed: LED_30.2, U3.18 (I13)
unnamed: LED_31.2, U3.17 (I14)
unnamed: LED_32.2, U3.16 (I15)
pwr for photoresistors: C1.1, C2.1, C3.1, C4.1, C5.1, C6.1, C7.1, C8.1, C9.1, C10.1, C11.1, C12.1, C13.1, C14.1, C15.1, C16.1, C17.1, C18.1, C19.1, C20.1, C21.1, C22.1, C23.1, C24.1, C25.1, C26.1, C27.1, C28.1, C29.1, C30.1, C31.1, C32.1, J1.1, J2.1, R1.1, R2.1, R3.1, R4.1, R5.1, R6.1, R7.1, R8.1, R9.1, R10.1, R11.1, R12.1, R13.1, R14.1, R15.1, R16.1, R17.1, R18.1, R19.1, R20.1, R21.1, R22.1, R23.1, R24.1, R25.1, R26.1, R27.1, R28.1, R29.1, R30.1, R31.1, R32.1, SW1.2 (B), TP1.1

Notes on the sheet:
Mounting Holes
LEDS
gnd test
XIAO-ESP32 & Photoresistors & Muxes
voltage test



Board: 2 copper layers, 177.9 x 169.6 mm, 194 parts (163 on the bottom side), 107 nets.

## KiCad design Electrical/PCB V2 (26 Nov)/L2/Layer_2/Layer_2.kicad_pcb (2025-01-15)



Board: 2 copper layers, 178.0 x 169.6 mm, 77 parts (48 on the bottom side), 55 nets.

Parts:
A1: TEENSY_4.0; MODULE_DEV-15583
C1, C2, C3, C4, C5, C6, C7, C8: 470u; CP_Radial_D8.0mm_P3.50mm
H1, H2, H3, H4, H5, H6, H7, H8, H9, H10, H11, H12, H13, H14, H15, H16, H17, H18, H19, H20: MountingHole; MountingHole_3.2mm_M3_DIN965_Pad
J1: XT60-M; AMASS_XT60-M
Q1, Q2, Q3, Q4: AON6354; 8-DFN (5x6)
R1, R2, R10, R11, R18, R19, R26, R27: 3K3; res0603
R3, R12, R20, R28: 10K; res0603
R4, R5, R6, R7, R8, R9, R13, R14, R15, R16, R17, R21, R22, R23, R24, R25, R29, R30, R31, R32, R33: 1K; res0603
SW1: SW_Nidec_CAS-120A1; PinHeader_1x03_P1.00mm_Vertical
SW2: SW_Push; PinHeader_1x03_P1.00mm_Vertical
U1, U2: LM2596ADJ
U3, U6, U7, U8: VNH5019ATR-E; IC_VNH5019ATR-E
U4, U5: XT30UPB-M

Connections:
+3V3: R1.2, R2.2, R10.2, R11.2, R18.2, R19.2, R26.2, R27.2, U1.2 (OUT), U5.P$1 (+)
/5v: U2.2 (OUT), U4.P$1 (+)
/12V: Q1.1 (S), Q1.2 (S), Q1.3 (S), Q2.1 (S), Q2.2 (S), Q2.3 (S), Q3.1 (S), Q3.2 (S), Q3.3 (S), Q4.1 (S), Q4.2 (S), Q4.3 (S), U3.12 (VBAT), U6.12 (VBAT), U7.12 (VBAT), U8.12 (VBAT)
/12v: J1.P (POS), SW2.2, U1.1 (VIN), U2.1 (VIN)
/Motor 1 EN A: R1.1, R4.1
/Motor 1 EN B: R2.1, R5.1
/Motor 1 Out A: U3.1 (OUTA), U3.25 (OUTA), U3.30 (OUTA), U3.HS2 (OUTA)
/Motor 1 Out B: U3.15 (OUTB), U3.16 (OUTB), U3.21 (OUTB), U3.HS3 (OUTB)
/Motor 2 EN A: R10.1, R13.1
/Motor 2 EN B: R11.1, R14.1
/Motor 2 Out A: U6.1 (OUTA), U6.25 (OUTA), U6.30 (OUTA), U6.HS2 (OUTA)
/Motor 2 Out B: U6.15 (OUTB), U6.16 (OUTB), U6.21 (OUTB), U6.HS3 (OUTB)
/Motor 3 EN A: R18.1, R21.1
/Motor 3 EN B: R19.1, R22.1
/Motor 3 Out A: U7.1 (OUTA), U7.25 (OUTA), U7.30 (OUTA), U7.HS2 (OUTA)
/Motor 3 Out B: U7.15 (OUTB), U7.16 (OUTB), U7.21 (OUTB), U7.HS3 (OUTB)
/Motor 4 EN A: R26.1, R29.1
/Motor 4 EN B: R27.1, R30.1
/Motor 4 Out A: U8.1 (OUTA), U8.25 (OUTA), U8.30 (OUTA), U8.HS2 (OUTA)
/Motor 4 Out B: U8.15 (OUTB), U8.16 (OUTB), U8.21 (OUTB), U8.HS3 (OUTB)
/Motor Driver: R6.1, R7.1, R15.1, R16.1, R23.1, R24.1, R31.1, R32.1, SW1.2 (B)
/PWM Motor 1: R3.1, R8.1
/PWM Motor 2: R12.1, R17.1
/PWM Motor 3: R20.1, R25.1
/PWM Motor 4: R28.1, R33.1
GND: C1.2, C2.2, C3.2, C4.2, C5.2, C6.2, C7.2, C8.2, J1.N (NEG), R3.2, R12.2, R20.2, R28.2, U1.3 (GND), U1.6 (GND), U2.3 (GND), U2.6 (GND), U3.18 (GNDB), U3.19 (GNDB), U3.20 (GNDB), U3.26 (GNDA), U3.27 (GNDA), U3.28 (GNDA), U4.P$2 (-), U5.P$2 (-), U6.18 (GNDB), U6.19 (GNDB), U6.20 (GNDB), U6.26 (GNDA), U6.27 (GNDA), U6.28 (GNDA), U7.18 (GNDB), U7.19 (GNDB), U7.20 (GNDB), U7.26 (GNDA), U7.27 (GNDA), U7.28 (GNDA), U8.18 (GNDB), U8.19 (GNDB), U8.20 (GNDB), U8.26 (GNDA), U8.27 (GNDA), U8.28 (GNDA)
unnamed: C1.1, C2.1, Q1.5 (D), Q1.6 (D), Q1.7 (D), Q1.8 (D), Q1.9 (D), U3.3 (VCC), U3.13 (VCC), U3.23 (VCC), U3.HS1 (VCC)
unnamed: C3.1, C4.1, Q2.5 (D), Q2.6 (D), Q2.7 (D), Q2.8 (D), Q2.9 (D), U6.3 (VCC), U6.13 (VCC), U6.23 (VCC), U6.HS1 (VCC)
unnamed: C5.1, C6.1, Q3.5 (D), Q3.6 (D), Q3.7 (D), Q3.8 (D), Q3.9 (D), U7.3 (VCC), U7.13 (VCC), U7.23 (VCC), U7.HS1 (VCC)
unnamed: C7.1, C8.1, Q4.5 (D), Q4.6 (D), Q4.7 (D), Q4.8 (D), Q4.9 (D), U8.3 (VCC), U8.13 (VCC), U8.23 (VCC), U8.HS1 (VCC)
unnamed: Q1.4 (G), U3.11 (CP)
unnamed: Q2.4 (G), U6.11 (CP)
unnamed: Q3.4 (G), U7.11 (CP)
unnamed: Q4.4 (G), U8.11 (CP)
unnamed: R9.1, SW1.3 (A)
unnamed: R4.2, U3.5 (ENA/DIAGA)
unnamed: R5.2, U3.9 (ENB/DIAGB)
unnamed: R6.2, U3.4 (INA)
unnamed: R7.2, U3.10 (INB)
unnamed: R8.2, U3.7 (PWM)
unnamed: R13.2, U6.5 (ENA/DIAGA)
unnamed: R14.2, U6.9 (ENB/DIAGB)
unnamed: R15.2, U6.4 (INA)
unnamed: R16.2, U6.10 (INB)
unnamed: R17.2, U6.7 (PWM)
unnamed: R21.2, U7.5 (ENA/DIAGA)
unnamed: R22.2, U7.9 (ENB/DIAGB)
unnamed: R23.2, U7.4 (INA)
unnamed: R24.2, U7.10 (INB)
unnamed: R25.2, U7.7 (PWM)
unnamed: R29.2, U8.5 (ENA/DIAGA)
unnamed: R30.2, U8.9 (ENB/DIAGB)
unnamed: R31.2, U8.4 (INA)
unnamed: R32.2, U8.10 (INB)
unnamed: R33.2, U8.7 (PWM)

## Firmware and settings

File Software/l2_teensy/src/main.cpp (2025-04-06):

#include <utility>
// #include <Adafruit_BNO08x.h>
#include "main.h"

using namespace std;
#define ll long long

//Functional Functions
void setupMotors() {
    //MOTOR 1
    pinMode(MOTOR_1_IN_A, OUTPUT);
    pinMode(MOTOR_1_IN_B, OUTPUT);
    pinMode(MOTOR_1_PWM, OUTPUT);
    analogWriteFrequency(MOTOR_1_PWM, 146484);

    //MOTOR 2
    pinMode(MOTOR_2_IN_A, OUTPUT);
    pinMode(MOTOR_2_IN_B, OUTPUT);
    pinMode(MOTOR_2_PWM, OUTPUT);
    analogWriteFrequency(MOTOR_2_PWM, 146484);

    //MOTOR 3
    pinMode(MOTOR_3_IN_A, OUTPUT);
    pinMode(MOTOR_3_IN_B, OUTPUT);
    pinMode(MOTOR_3_PWM, OUTPUT);
    analogWriteFrequency(MOTOR_3_PWM, 146484);

    //MOTOR 4
    pinMode(MOTOR_4_IN_A, OUTPUT);
    pinMode(MOTOR_4_IN_B, OUTPUT);
    pinMode(MOTOR_4_PWM, OUTPUT);
    analogWriteFrequency(MOTOR_4_PWM, 146484);

    Serial.println("Motors pinModes defined (by right...)");
}

double clipAngleTo360(double angle) {
    angle = fmod(angle, 360);
    return angle < 0 ? angle + 360 : angle;
}

pair<double, double> getSerial_L1() {
    if (Serial_L1.available()) {
        String received = Serial_L1.readStringUntil('\n');
        Serial.print("Received from ESP32C3: ");
        Serial.println(received);
        
        // Optional: Trim any trailing \r or whitespace
        received.trim();
        // Parse the line
        int spaceIndex = received.indexOf(' ');
        if (spaceIndex != -1) {
            String angleStr = received.substring(0, spaceIndex);
            String sizeStr = received.substring(spaceIndex + 1);

            double angle = angleStr.toFloat();
            double size = sizeStr.toFloat();

            return {angle, size};
            // Serial.print("Angle: ");
            // Serial.println(angle);
            // Serial.print("Size: ");
            // Serial.println(size);
        }
        else {
            // Serial.println("Malformed line: missing space");
            return {NAN, NAN};
        }
    }
}

// void setReports(void) {
//   Serial.println("Setting desired reports");
//   if (! bno08x.enableReport(SH2_GAME_ROTATION_VECTOR)) {
//     Serial.println("Could not enable game vector");
//   }
// }

// void setupIMU() {
//       if (!bno08x.begin_UART(&Serial_IMU)) {  // Requires a device with > 300 byte UART buffer!
//           while (1) {
//           Serial.println("Failed to find BNO08x chip");
//           }
//       }
//       Serial.println("BNO08x Found!");
//       setReports();
// }

// Move the robot in any direction using your 34.4° X-drive setup.
// angleDeg: movement direction in degrees (0° = forward, 90° = right)
// speed:    how fast to move (0.0 to 1.0)
// omega:    how fast to rotate (positive = clockwise)
void moveRobot(double angleDeg, double speed, double omega) {
    double angleRad = angleDeg * DEG_TO_RAD;

    double vx = speed * cos(angleRad);  // rightward
    double vy = speed * sin(angleRad);  // forward

    // X-drive projection
    double m1 = vy + vx + omega;  // Front Left
    double m2 = vy - vx + omega; // Back Left  (needs inversion)
    double m3 = vy + vx - omega; // Back Right
    double m4 = vy - vx - omega; // Front Right (needs inversion)

    // Normalize
    double maxMag = max({abs(m1), abs(m2), abs(m3), abs(m4), 1.0});
    m1 /= maxMag;
    m2 /= maxMag;
    m3 /= maxMag;
    m4 /= maxMag;

    // Invert Motor 2 and 4 to fix wrong spin direction
    m2 = -m2;
    m4 = -m4;

    auto setMotor = [](int inA, int inB, int pwmPin, double power) {
        bool forward = (power >= 0);
        int pwmVal = abs(power * 255);
        digitalWrite(inA, forward ? HIGH : LOW);
        digitalWrite(inB, forward ? LOW : HIGH);
        analogWrite(pwmPin, pwmVal);
    };

    setMotor(MOTOR_1_IN_A, MOTOR_1_IN_B, MOTOR_1_PWM, m1);   // Front Left (OK)
    setMotor(MOTOR_2_IN_A, MOTOR_2_IN_B, MOTOR_2_PWM, m2);  // Back Left (flip)
    setMotor(MOTOR_3_IN_A, MOTOR_3_IN_B, MOTOR_3_PWM, m3);   // Back Right (OK)
    setMotor(MOTOR_4_IN_A, MOTOR_4_IN_B, MOTOR_4_PWM, m4);  // Front Right (flip)
}

void rotateToAngle(double targetAngle) {
    // Wrap angle to [0, 360)
    targetAngle = fmod(targetAngle, 360);
    if (targetAngle < 0) targetAngle += 360;

    // Error = how far we are off (signed)
    double angleError = targetAngle;
    if (angleError > 180) angleError -= 360;  // signed shortest path

    if (abs(angleError) < 5) {
        // Aligned — stop rotating
        moveRobot(0, 0, 0);
    } else if (angleError < 0) {
        // Target is to the left — spin left
        moveRobot(0, 0, -1.0);
    } else {
        // Target is to the right — spin right
        moveRobot(0, 0, 1.0);
    }
}

void getCamData() {
    if (Serial_CAM.available()) {
        String received = Serial_CAM.readStringUntil('\n');
        Serial.print("Received from Teensy: ");
        Serial.println(received);
        received.trim();
        // Prepare 12 double variables
        double values[12];

        int index = 0;
        int from = 0;

        while (index < 12) {
            int space = received.indexOf(' ', from);
            if (space == -1) space = received.length();
            String token = received.substring(from, space);
            from = space + 1;

            values[index] = (token == "none") ? NAN : token.toFloat(); // use nan for missing blobs
            index++;
        }

        ballX = values[0];
        if (!isnan(ballX)) lastballX = ballX;
        ballY = values[1];
        if (!isnan(ballY)) lastballY = ballY;
        ballAngle = values[2];
        if (!isnan(ballAngle)) lastballAngle = ballAngle;
        ballDistance = values[3];
        if (!isnan(ballDistance)) lastballDistance = ballDistance;

        blueGoalX = values[4];
        if (!isnan(blueGoalX)) lastblueGoalX = blueGoalX;
        blueGoalY = values[5];
        if (!isnan(blueGoalY)) lastblueGoalY = blueGoalY;
        blueGoalAngle = values[6];
        if (!isnan(blueGoalAngle)) lastblueGoalAngle = blueGoalAngle;
        blueGoalDistance = values[7];
        if (!isnan(blueGoalDistance)) lastblueGoalDistance = blueGoalDistance;

        yellowGoalX = values[8];
        if (!isnan(yellowGoalX)) lastyellowGoalX = yellowGoalX;
        yellowGoalY = values[9];
        if (!isnan(yellowGoalY)) lastyellowGoalY = yellowGoalY;
        yellowGoalAngle = values[10];
        if (!isnan(yellowGoalAngle)) lastyellowGoalAngle = yellowGoalAngle;
        yellowGoalDistance = values[11];
        if (!isnan(yellowGoalDistance)) lastyellowGoalDistance = yellowGoalDistance;

        Serial.println("=== BALL DATA ===");
        Serial.print("ballX: "); Serial.println(ballX);
        Serial.print("ballY: "); Serial.println(ballY);
        Serial.print("ballAngle: "); Serial.println(ballAngle);
        Serial.print("ballDistance: "); Serial.println(ballDistance);

        Serial.println("=== BLUE GOAL ===");
        Serial.print("blueGoalX: "); Serial.println(blueGoalX);
        Serial.print("blueGoalY: "); Serial.println(blueGoalY);
        Serial.print("blueGoalAngle: "); Serial.println(blueGoalAngle);
        Serial.print("blueGoalDistance: "); Serial.println(blueGoalDistance);

        Serial.println("=== YELLOW GOAL ===");
        Serial.print("yellowGoalX: "); Serial.println(yellowGoalX);
        Serial.print("yellowGoalY: "); Serial.println(yellowGoalY);
        Serial.print("yellowGoalAngle: "); Serial.println(yellowGoalAngle);
        Serial.print("yellowGoalDistance: "); Serial.println(yellowGoalDistance);
    }
}

//Debugging Functions
bool debugging = true;

void test_MOTORs() {
    if (debugging) {
        digitalWrite(MOTOR_1_IN_A, HIGH);
        digitalWrite(MOTOR_1_IN_B, LOW);
        analogWrite(MOTOR_1_PWM, 255);
        digitalWrite(MOTOR_2_IN_A, HIGH);
        digitalWrite(MOTOR_2_IN_B, LOW);
        analogWrite(MOTOR_2_PWM, 255);
        digitalWrite(MOTOR_3_IN_A, HIGH);
        digitalWrite(MOTOR_3_IN_B, LOW);
        analogWrite(MOTOR_3_PWM, 255);
        digitalWrite(MOTOR_4_IN_A, HIGH);
        digitalWrite(MOTOR_4_IN_B, LOW);
        analogWrite(MOTOR_4_PWM, 255);
        Serial.println("Motors should spin...");
    }
}

void test_MOTOR_1() {
    for (int x = 0; x < 255; x++) { 
        digitalWrite(MOTOR_1_IN_A, LOW);
        digitalWrite(MOTOR_1_IN_B, HIGH);
        analogWrite(MOTOR_1_PWM, x);
        delay(10);
    }
    for (int x = 255; x > 0; x--) { 
        digitalWrite(MOTOR_1_IN_A, LOW);
        digitalWrite(MOTOR_1_IN_B, HIGH);
        analogWrite(MOTOR_1_PWM, x);
        delay(1);
    }
    for (int x = 0; x < 255; x++) {
        digitalWrite(MOTOR_1_IN_A, HIGH);
        digitalWrite(MOTOR_1_IN_B, LOW);
        analogWrite(MOTOR_1_PWM, x);
        delay(1);
    }
    for (int x = 255; x > 0; x--) { 
        digitalWrite(MOTOR_1_IN_A, HIGH);
        digitalWrite(MOTOR_1_IN_B, LOW);
        analogWrite(MOTOR_1_PWM, x);
        delay(10);
    }
}

//Actual code
void setup() {
    Serial.begin(115200);
    // while (!Serial) { ; } // Wait for serial connection
    Serial_L1.begin(9600);
    Serial_L3.begin(9600);
    Serial_IMU.begin(115200);
    Serial_CAM.begin(115200);
    Serial.println("UART Intialised... (by right)");
    if (debugging) {
        Serial.println("Debugging");
    }
    else {
        Serial.println("Not Debugging");
    }
    setupMotors();
    // test_MOTORs();
}

void loop() {
    //ignore boundaries
    getCamData();
    //move towards ball
    if (!isnan(ballAngle) || !isnan(ballDistance)) {
        //ball detected -> move towards ball
        if (ballDistance > 40) {
            //not close enough to ball, move towardsball
            moveRobot(ballAngle, 1.6, (ballAngle > 180) ? -.2 : .2);
        }
        else {
            // near ball -> circle, align and kick towards goal
            
            //check if opps goal in sight
            if (!isnan((oppsGoal == "blue") ? blueGoalAngle : yellowGoalAngle)) {
                //opps goal can see, align and shoot

                //check if aligned
                if (abs(((oppsGoal == "blue") ? blueGoalAngle : yellowGoalAngle) - (ballAngle)) < 10) {
                    //aligned -> ram forward full speed
                    moveRobot(ballAngle, 1.6, (ballAngle > 180) ? -.2 : .2);
                }
                else {
                    //not aligned -> circle
                    moveRobot(clipAngleTo360(ballAngle+90), 1.6, (ballAngle > 180) ? -.2 : .2);
                }
            }
            else {
                //cannot see opps goal -> prob means can see own goal
                double ownGoalAngle = (strcmp(oppsGoal, "blue") == 0) ? blueGoalAngle : yellowGoalAngle;

                if (!isnan(ownGoalAngle)) {
                    // Own goal is visible — move away from it (180° opposite)
                    double avoidAngle = clipAngleTo360(ownGoalAngle + 180);
                    Serial.println("Opponent goal not visible — moving away from own goal");
                    moveRobot(avoidAngle, 1.0, 0.1);  // slightly curve away to reorient
                }
                else {
                    // Neither goal visible — spiral to scan
                    static double spiralAngle = 0;
                    spiralAngle = clipAngleTo360(spiralAngle + 10); // increment slowly
                    Serial.println("Both goals not visible — spiral search");
                    moveRobot(spiralAngle, 0.5, 0.2);
                }
            }
        }
    }
    else {
        // Ball not seen — go to field center based on goal info or spiral
        double ownGoalAngle = (strcmp(oppsGoal, "blue") == 0) ? blueGoalAngle : yellowGoalAngle;
        double oppsGoalAngle = (strcmp(oppsGoal, "blue") == 0) ? yellowGoalAngle : blueGoalAngle;

        if (!isnan(ownGoalAngle)) {
            // Move toward field center: away from own goal
            double centerApproachAngle = clipAngleTo360(ownGoalAngle + 180);
            Serial.println("⚠️ Ball not visible — moving away from own goal to center");
            moveRobot(centerApproachAngle, 1.0, 0.1);
        } else if (!isnan(oppsGoalAngle)) {
            // Move slightly backward from opps goal (safer fallback)
            double centerApproachAngle = clipAngleTo360(oppsGoalAngle + 180);
            Serial.println("⚠️ Ball not visible — moving away from opponent goal");
            moveRobot(centerApproachAngle, 0.8, -0.1);
        } else {
            // No goalposts visible — spiral to search for ball/goal
            static double searchAngle = 0;
            searchAngle = clipAngleTo360(searchAngle + 8);
            Serial.println("⚠️ Ball and goals not visible — spiraling to search");
            moveRobot(searchAngle, 0.6, 0.2);
        }
    }
}

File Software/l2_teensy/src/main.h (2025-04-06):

#ifndef TEENSY_H
#define TEENSY_H

#include <Arduino.h>

//Goal
#define oppsGoal "blue"
// #define oppsGoal "yellow"

//MOTOR 1
#define MOTOR_1_IN_A 12
#define MOTOR_1_IN_B 11
#define MOTOR_1_PWM 3

//MOTOR 2
#define MOTOR_2_IN_A 10
#define MOTOR_2_IN_B 9
#define MOTOR_2_PWM 2

//MOTOR 3
#define MOTOR_3_IN_A 22
#define MOTOR_3_IN_B 23
#define MOTOR_3_PWM 1

//MOTOR 4
#define MOTOR_4_IN_A 6
#define MOTOR_4_IN_B 5
#define MOTOR_4_PWM 0

//Serials
#define Serial_L1 Serial2 // Serial to L1 Esp32c3
#define Serial_L3 Serial5 // Serial to L3 Esp32c3
#define Serial_CAM Serial3 // Serial to CAM
#define Serial_IMU Serial4 // Serial to IMU

//Cam

//ball
double ballX = NAN;
double ballY = NAN;
double ballAngle = NAN;
double ballDistance = NAN;
//last known positions
double lastballX = NAN;
double lastballY = NAN;
double lastballAngle = 340;
double lastballDistance = NAN;

//blue goal
double blueGoalX = NAN;
double blueGoalY = NAN;
double blueGoalAngle = NAN;
double blueGoalDistance = NAN;
//last known positions
double lastblueGoalX = NAN;
double lastblueGoalY = NAN;
double lastblueGoalAngle = NAN;
double lastblueGoalDistance = NAN;

//yellow goal
double yellowGoalX = NAN;
double yellowGoalY = NAN;
double yellowGoalAngle = 0;
double yellowGoalDistance = NAN;
//last known positions
double lastyellowGoalX = NAN;
double lastyellowGoalY = NAN;
double lastyellowGoalAngle = 180;
double lastyellowGoalDistance = NAN;

//Functional Function Prototypes
void setupMotors();
void test_MOTOR_1();

bool firstloop = true;

#endif  // TEENSY_H

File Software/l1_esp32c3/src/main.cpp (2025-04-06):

#include "main.h"

#include <algorithm>
#include <array>
#include <vector>
#include <array>
#include <deque>

//Functional Functions
void setupMux() {
    pinMode(M1, INPUT);
    pinMode(M2, INPUT);
    pinMode(S0, OUTPUT);
    pinMode(S1, OUTPUT);
    pinMode(S2, OUTPUT);
    pinMode(S3, OUTPUT);
    Serial.println("MUX Setup Completed... (by right)");
}

void selectMuxChannel(int channel) {
    digitalWrite(S0, channel & 0x01);
    digitalWrite(S1, (channel >> 1) & 0x01);
    digitalWrite(S2, (channel >> 2) & 0x01);
    digitalWrite(S3, (channel >> 3) & 0x01);
}

int readMux1Channel(int channel) {
    selectMuxChannel(channel);
    int ldr_value = analogRead(M1);
    // Serial.println(ldr_value); 
    return ldr_value; 
}

int readMux2Channel(int channel) {
    selectMuxChannel(channel);
    int ldr_value = analogRead(M2);
    // Serial.println(ldr_value); 
    return ldr_value; 
}

// Clips an angle to the range (-180, 180]
double clipAngleTo180(double angle) {
    angle = fmod(angle, 360);
    return angle > 180 ? angle - 360 : (angle < -180 ? angle + 360 : angle);
}

// Clips an angle to the range [0, 360)
double clipAngleTo360(double angle) {
    angle = fmod(angle, 360);
    return angle < 0 ? angle + 360 : angle;
}

// Finds the difference between two angles, in the range [0, 360)
double angleDifference(double leftAngle, double rightAngle) {
    return clipAngleTo360(rightAngle - leftAngle);
}

// Finds the smaller difference between two angles, in the range [0, 180]
double smallerAngleDifference(double leftAngle, double rightAngle) {
    const auto angle = angleDifference(leftAngle, rightAngle);
    return fmin(angle, 360 - angle);
}

// Finds the angle bisector between two angles, in the range [0, 360)
double angleBisector(double leftAngle, double rightAngle) {
    return clipAngleTo360(leftAngle + smallerAngleDifference(leftAngle, rightAngle) / 2);
}

void checkLightRing() {
    int ldr = 0;

    //cycle thru mux 1 to check if ldr value above treshhold (treshhold set in light_ring.h)
    //if above treshhold, set ldr value in ldr_threshold_pass: set as true. else set as false
    for (int mux1 = 0; mux1 < 16; mux1++) {
        int ldrVal = readMux1Channel(mux1);
        ldr_values[ldr] = ldrVal;
        if (ldrVal >= ldr_threshold) {
            ldr_threshold_pass[ldr] = true;
        }
        else {
            ldr_threshold_pass[ldr] = false;
        }
        ldr++;
    }

    //cycle thru mux 2
    for (int mux2 = 0; mux2 < 16; mux2++) {
        int ldrVal = readMux2Channel(mux2);
        ldr_values[ldr] = ldrVal;
        if (ldrVal >= ldr_threshold) {
            ldr_threshold_pass[ldr] = true;
        }
        else {
            ldr_threshold_pass[ldr] = false;
        }
        ldr++;
    }

    for (int i = 0; i < 16; i++) {
        filtered_ldr_threshold_pass[i] = ldr_threshold_pass[i*2];
        filtered_ldr_values[i] = ldr_values[i*2];
    }


}

pair<double, double> findLine() {
    //from senrobo github code-int23
    //adding ldrs detecting the line to vector matches
    vector<uint8_t> matches;
    matches.reserve(16);
    for (int i = 0; i < 16; i++) {
        if (filtered_ldr_threshold_pass[i]) matches.push_back(i);
    }

    //less than 2 matches detected, not on the line
    if (matches.size() <= 1) return {NAN, NAN};

    //find scope of the line

    double lineStartAngle = NAN, lineEndAngle = NAN;
    
    //iterate thru all combinations of matching indices (cool work here) and find the pair furthest apart
    
    double maxAngleDifference = 0;
    for (uint8_t i = 0; i < matches.size()-1; i++) {
        for (uint8_t j = i+1; j < matches.size(); j++) {
            //getting bearings of ldrs
            const auto angleI = matches[i]*22.5;
            const auto angleJ = matches[j]*22.5;
            //current angle difference between ldr i and j
            const auto angleDifference = smallerAngleDifference(angleI, angleJ);
            if (angleDifference > maxAngleDifference) {
                maxAngleDifference = angleDifference;
                lineStartAngle = angleI;
                lineEndAngle = angleJ;
            }
        }
    }

    //This should not happen, but just in case (quoted)
    if (isnan(lineStartAngle) || isnan(lineEndAngle)) return {NAN, NAN};

    //Calculate the line angle bisector and size
    if (lineEndAngle - lineStartAngle > 180) swap(lineStartAngle, lineEndAngle);
    
    const auto lineAngleBisector = angleBisector(lineStartAngle, lineEndAngle);
    //Let line size be the ratio of the cluster size to 180°, so it's in [0, 1]
    const auto lineSize = maxAngleDifference / 180.0;

    return {lineAngleBisector, lineSize};
}

void communicateSerial(double angle, double size) {
    Serial_L1.print(angle);
    Serial_L1.print(" ");
    Serial_L1.println(size);
}

//Debugging Functions
void readLDR1() {
    digitalWrite(S0, HIGH);
    digitalWrite(S1, LOW);
    digitalWrite(S2, LOW);
    digitalWrite(S3, LOW);
    Serial.println(analogRead(M1));
}

void readLDRs() {
    checkLightRing();
    Serial.println();
    Serial.print("LDRs: ");
    for (int i = 0; i < 32; i++) {

        // if (ldr_threshold_pass[i]) {
        //     Serial.print(1);
        // }
        // else {
        //     Serial.print(0);
        // }
        // Serial.print(filtered_ldr_values[i]);
        Serial.print(ldr_values[i]);
        Serial.print(" | ");
    }
}

void setupSolenoid() {
    pinMode(Solenoid, OUTPUT);
    digitalWrite(Solenoid, LOW);
}

void kickSolenoid() {
    digitalWrite(Solenoid, HIGH);
    delay(500);
    digitalWrite(Solenoid, LOW);
}

// Run the calibration routine
void printLightRingCalibration() {
    // min = green (field), max = white (line)
    uint16_t min[16], max[16];
    for (int i = 0; i < 16; ++i) {
        min[i] = 0xFFFF;
        max[i] = 0x0000;
    }

    const auto endTime = millis() + 1000;
    while (millis() < endTime) {
        for (uint8_t i = 0; i < 16; ++i) {
            const auto value = filtered_ldr_values[i];
            if (value < min[i]) min[i] = value;
            if (value > max[i]) max[i] = value;
        }
    }

    // Print the thresholds (averages of min and max)
    Serial.printf("Thresholds: {");
    for (uint8_t i = 0; i < 16; ++i) {
        // TODO: Find a more accurate way to calculate the threshold
        const auto threshold = (max[i] + min[i]) / 2;
        Serial.printf("%d, ", (uint16_t)threshold);
    }
    Serial.printf("}\n");
}

//debug threshold
void printLDRThreshold() {
    checkLightRing();
    for (int i = 0; i < 16; i++) {
        Serial.print(filtered_ldr_threshold_pass[i]);
        Serial.print(" | ");
    }
    Serial.println();
}

//Actual Code
void setup() {
    Serial.begin(115200);
    Serial_L1.begin(9600, SERIAL_8N1, -1, -1);
    analogReadResolution(12);
    setupMux();
    // setupSolenoid();
}
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

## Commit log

2024-11-21 L1 with light ring and photo resistors - pcb design cos cx slowww
    as of 21 11 2024
    [ALS-PT19-315C_L177_TR8.step, ESP32-S3-WROOM-1U-N4.step, Parts List L1 V1.xlsx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]
2024-11-21 updated ver of L1 with buck converter 21 11 2024
    new ver xcbhc
    [LM2596ADJ.step, l1 v1.kicad_sch]
2024-11-22 create mech and software folders and renamed elec fodler to maintain consistenccy between folder names
    [ALS-PT19-315C_L177_TR8.step, ESP32-S3-WROOM-1U-N4.step, LM2596ADJ.step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]
2024-11-22 renamed volatage divider to dc -dc converted for accurate naming, moved some text around becuz easier to read
    [l1 v1.kicad_sch]
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2024-11-23 idk what i changed anyway i felt like uploading
    [Middle Layer.step, Side Layer 1.step]
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2024-11-26 new version with the thingy wutht the light ringt
    i need the photoresistors to be in yikai to do
    [l1 v1.kicad_pcb]
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2024-11-26 edge cuts xt 30 adn the essp 32 to be added
    [XT30UPB-M.step, l1 v1.kicad_pcb, l1 v1.kicad_sch]
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2024-11-26 wired pcb minus esp 32 wiring
    to be checked by haoyuan/haojun not done 100%
    [CD74HC4067SM96G4.step, ESP32-WROOM-32D-N4.step, l1 v1.kicad_pcb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]
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2024-11-26 wires half done to br finiished @chenyikaithegoat to wire esp32 and i do the wiring finish
    [l1 v1.kicad_pcb, l1 v1.kicad_sch]
2024-11-26 l1v2 with photoresistors minus wired
    to be finished on 27 now
    [ALS-PT19-315C_L177_TR8.step, CD74HC4067SM96G4.step, ESP32-S3-WROOM-1U-N4.step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]
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2025-01-03 layer 2 no pcb
    i added yikais version of layer two, yet to be reviwed by seniors
    [Layer_2.kicad_pcb, Layer_2.kicad_sch]
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2025-01-05 did led wiring to 3v3 and to muxes.
    [L1 Layout.dxf, l1v2.kicad_pcb, l1v2.kicad_sch]
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2025-01-06 added l2 dxf, did some more stuff to l1
    [L2 Layout.dxf, l1v2.kicad_pcb, l1v2.kicad_sch]
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2025-01-06 changed some stuff for l1, uploaded updated l2 layout
    [L2 Layout.dxf, l1v2.kicad_pcb]
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2025-01-08 added l2 dxf, idk what else sth about the pcb
    [L2 Layout.dxf, l1v2.kicad_pcb]
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2025-01-10 to be fix
    [Layer_2.kicad_pcb, Layer_2.kicad_sch]
2025-01-13 to do
    add sensor fix motor drivers and teensy
    [Layer_2.kicad_pcb, Layer_2.kicad_sch]
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2025-01-15 to be done : solve the teensy mystyery
    [DEV-15583.step, Layer_2.kicad_pcb, Layer_2.kicad_sch]
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2025-01-18 experimented with logo on silkscreen on l1, updated and cleaned up svg file to be ready for improting into kicad, decrases logo to 1cm2 size
    [l1v2.kicad_pcb]
2025-01-21 Update PCB V2 ( 26 Nov) before renaming
    [l1v2.kicad_pcb, l1v2.kicad_sch]
2025-01-21 Rename PCB V2 ( 26 Nov) to PCB V2 (26 Nov)
    [ALS-PT19-315C_L177_TR8.step, CD74HC4067SM96G4.step, DEV-15583.step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]
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2025-01-24 THIS IS CORRECT VERSION WITH RESTORED STASHED CHANGES STUGFFFF
    [L1.kicad_pcb]
2025-01-24 fix fills
    [Layer 2.kicad_pcb]
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2025-02-01 updated l1 dxf to v2, l2 dxf to v3
    [OneAndOnlyDxf v2.dxf, OneAndOnlyDxf v3.dxf]
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2025-02-02 mounting hole some issue idk
    [Layer 2.kicad_pcb]
2025-02-05 added l2 dxf v4, started on l1 again
    [L1.kicad_sch, OneAndOnlyDxf v4.dxf]
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2025-02-05 Updated L3
    chen xuan wants to do when i gone
    [layer 3 schematics 24 jan.kicad_pcb]
2025-02-05 halfway done with motor drivers footprint vias are gay
    [Layer 2.kicad_pcb, Layer 2.kicad_sch]
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2025-02-06 yay fixed motor driver do rest mr cos tired djbfj
    [Layer 2.kicad_pcb, Layer 2.kicad_sch]
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2025-02-07 7 feb update!!! stop at pull up res
    [layer 3 schematics 24 jan.kicad_pcb, layer 3 schematics 24 jan.kicad_sch]
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2025-02-09 motor drivers someone done ish ig this is from yesterday
    [Layer 2.kicad_pcb]
2025-02-09 last motor driver to be done and jst
    [Layer 2.kicad_pcb, Layer 2.kicad_sch, layer 3 schematics 24 jan.kicad_pcb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]
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2025-02-09 motor drivers r done to be done tmr: diodes footbrint buckies boost capacitors and teensy pwm and motor feedback wiring
    [Layer 2.kicad_pcb, Layer 2.kicad_sch]
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2025-02-10 i think i added the solenoid boost in this idk
    [Layer 2.kicad_pcb]
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2025-02-10 small adjustments made to l3 (moved a little silkscreen)
    [L3.kicad_pcb]
2025-02-10 did some stuff with l3, settke another day
    [L3.kicad_pcb, L3.kicad_sch]
2025-02-10 kicad crashed ufekg still have like 70 errors
    [Layer 2.kicad_pcb, Layer 2.kicad_sch]
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2025-02-12 v4 converted to v3 tho v4 sounds cooler than v3 and er one moter driver done buckies and boost done to be done is js teensy wiring anf drivers+l3jst
    [Layer 2.kicad_pcb, Layer 2.kicad_sch, OneAndOnlyDxf v2.dxf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]
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2025-02-13 fixed l1 and l3, awaiting vetting
    [L1.kicad_pcb, L3.kicad_pcb]
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2025-02-14 fixed l1 and l3
    [L1.kicad_pcb, Mirror.step, OneAndOnlyDxf v4.dxf]
2025-02-14 no idea what happened to l3 and l1 but they changed
    [L3.kicad_pcb]
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2025-02-14 added some changes kianwu suggested to l1 (changed clearences etc)
    [L1.kicad_pcb]
2025-02-15 show new l1 to haoyuun shd be somewhat done @Ng-Chen-Xuan if need make some tweaks
    [L1.kicad_pcb]
2025-02-15 pcb shd be done errors are footprint problmes idk if we shd ignore
    [Layer 2.kicad_pcb, Layer 2.kicad_sch]
2025-02-15 might need to add test point but otherwise done
    [Layer 2.kicad_pcb]
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2025-02-15 fixed abit of l2
    [Layer 2.kicad_pcb]
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2025-02-17 swap rx tx
    [Layer 2.kicad_pcb, Layer 2.kicad_sch]
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2025-02-18 fix errors?!
    [L1.kicad_pcb, Layer 2.kicad_pcb]
2025-02-18 tried to fix some gay looking stuff
    [Layer 2.kicad_pcb]
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2025-02-21 fixed l1 boost, started on activation circuit
    [L1.kicad_pcb, L1.kicad_sch, L3.kicad_pcb]
2025-02-21 fixed l1 solenoid mosfet
    [L1.kicad_pcb, L1.kicad_sch]
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2025-02-22 exported l1 step file, added some 3d models to l1, spammed save
    [L1.kicad_pcb, L1.kicad_sch]
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2025-02-23 fixed diode and activation cirucit for solenoid (l1), exported step files of all layers
    [L1.kicad_pcb, L1.kicad_sch, L3.kicad_pcb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]
2025-02-24 i think ii need to change er tjst idk to where though
    [Layer 2.kicad_pcb]
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2025-02-26 flipped l3 jst, added l3 step
    [L3.kicad_pcb, L3.step]
2025-02-26 added l3 new step, added new testpoint, fixed some l3
    [L3.kicad_pcb, L3.step]
2025-02-26 fixed l3, added new l3 model
    [L3.kicad_pcb, L3.step]
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2025-02-26 added some stuff to parts list, fixed l1 schematics to fit parts in lab abit more, pending change of activaition circuit
    [L1.kicad_pcb, L1.kicad_sch]
2025-02-26 deleted some l3 stuff to clear up folders, open and closed l3
    [L3.kicad_pcb, L3.kicad_sch]
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2025-02-27 did some touching up made traces less cursed with gnd fills in between and made schmeatics look better with aligned boxes
    [Layer 2.kicad_pcb, Layer 2.kicad_sch]
2025-02-27 solved 3v3 thingy for l2
    [Layer 2.kicad_pcb]
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2025-02-28 fixed l1 solenoid activation circuit
    [L1.kicad_pcb, L1.kicad_sch]
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2025-02-28 fixed caps again
    [L2.step, Layer 2.kicad_pcb]
2025-02-28 fixed l2 caps positon, export new l2 step. fixed l3 jst from eh to xh, realised need to flip l2 jst
    [L2.step, L3.kicad_pcb, L3.kicad_sch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]
2025-02-28 fixed l2 switch jst position,
    [L2.step, Layer 2.kicad_pcb]
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2025-02-28 fixed l3 edge cut in 5min what an accomplishment
    [L3.kicad_pcb, OneAndOnlyDxf v5.dxf]
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2025-03-01 shopuld have fixed l1 and l3 based on kian wu comments
    [L1.kicad_pcb, L3.kicad_pcb]
2025-03-01 idk i think i fixed everything lol+step file
    [L2.step, Layer 2.kicad_pcb, Layer 2.kicad_sch]
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2025-03-02 i kinda forgot what else i changed i js got a new bom
    [Layer 2.kicad_pcb]
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2025-03-03 Revert "ugly ill try to solve it js iignore this ig"
    This reverts commit 7661a4ec2d23ca034bc6a6c45d6a88a4925001ca.
    [Layer 2.kicad_pcb]
2025-03-03 Revert "idl symmerty seems very cursed idk"
    This reverts commit 71007cebac8688711b86db00dc9c9779fd03cb35.
    [Layer 2.kicad_pcb]
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2025-03-03 erm moved 2 drivers flip
    [L2.step, Layer 2.kicad_pcb, Layer 2.kicad_sch]
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2025-03-05 fixed l2
    [Layer 2.kicad_pcb, Layer 2.kicad_sch]
2025-03-05 fixed l2 again
    [Layer 2.kicad_pcb]
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2025-03-06 fixed l1 jst position
    [L1.kicad_pcb, Layer 2.kicad_pcb]
2025-03-06 did some changes to l2 still need to link everything up pos are symmetric though
    [Layer 2.kicad_pcb]
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2025-03-06 swapped l1 rx n tx
    [L1.kicad_pcb, L1.kicad_sch]
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2025-03-06 fixed l2. IM A GENIUS I CREATED RULE AREA
    [Layer 2.kicad_pcb, Layer 2.kicad_sch, OneAndOnlyDxf v13.dxf]
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2025-03-08 fix teensy
    [Layer 2.kicad_pcb]
2025-03-08 fixed l2, exported new l2 and l3 steps
    [L2.step, L3.kicad_pcb, L3.kicad_sch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]
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2025-03-08 fixed problems drc found on l2
    [Layer 2.kicad_pcb]
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2025-03-09 fix except mosfet
    [Layer 2.kicad_pcb, Layer 2.kicad_sch]
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2025-03-09 i think i fixed everything
    [L3.kicad_pcb, Layer 2.kicad_pcb]
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2025-03-09 fixed l2 and l3, new l2 and l3 step
    [L2.step, L3.kicad_pcb, L3.step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]
2025-03-09 fixed l2 n l3, production files for all layers, step for l2 and l3
    [L2.step, Layer 2.kicad_pcb, bom.csv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]
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2025-03-17 wrote l1 code, fixed l1 pcb
    [L1.kicad_pcb, L1.kicad_sch, OneAndOnlyDxf v8.dxf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]
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2025-03-18 fixed l1
    [L1.kicad_pcb, OneAndOnlyDxf v10dxf.dxf, OneAndOnlyDxf v9dxf.dxf]
2025-03-18 fixed l1 pcb
    [L1.kicad_pcb]
2025-03-19 idk if i fixed l1 code
    [main.cpp, main.h]
2025-03-19 fixed? removed A from analog pin definitions
    [main.h]
2025-03-21 fixed l2 bucks
    [L1.step, L2.step, Layer 2.kicad_pcb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]
2025-03-29 fixed wheels and proabbly kicker
    [3D Printed v11 v2.3mf, ALL Files.step, KICK SURFACE.3mf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]
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
